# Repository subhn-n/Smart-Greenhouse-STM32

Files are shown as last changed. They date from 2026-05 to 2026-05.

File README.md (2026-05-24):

# 🌱 Smart Greenhouse Controller

<p align="center">
  
  
  
  
  
  
  
</p>

---

## 📖 Overview

This project is a **smart greenhouse controller** designed around an **STM32L476RG** microcontroller.  
The goal was to create an embedded system capable of:

- 🌡 Monitoring temperature
- 💧 Monitoring soil humidity
- ☀️ Measuring ambient light
- 🚿 Controlling a water pump
- 🌬 Controlling a cooling fan
- 💡 Controlling LED lighting using PWM
- 📱 Communicating wirelessly through Bluetooth

The project combines:

- Embedded programming
- Power electronics
- PCB design
- Sensor acquisition
- Bluetooth communication
- PWM control
- Rapid prototyping

---

# 🧠 System Architecture

<p align="center">
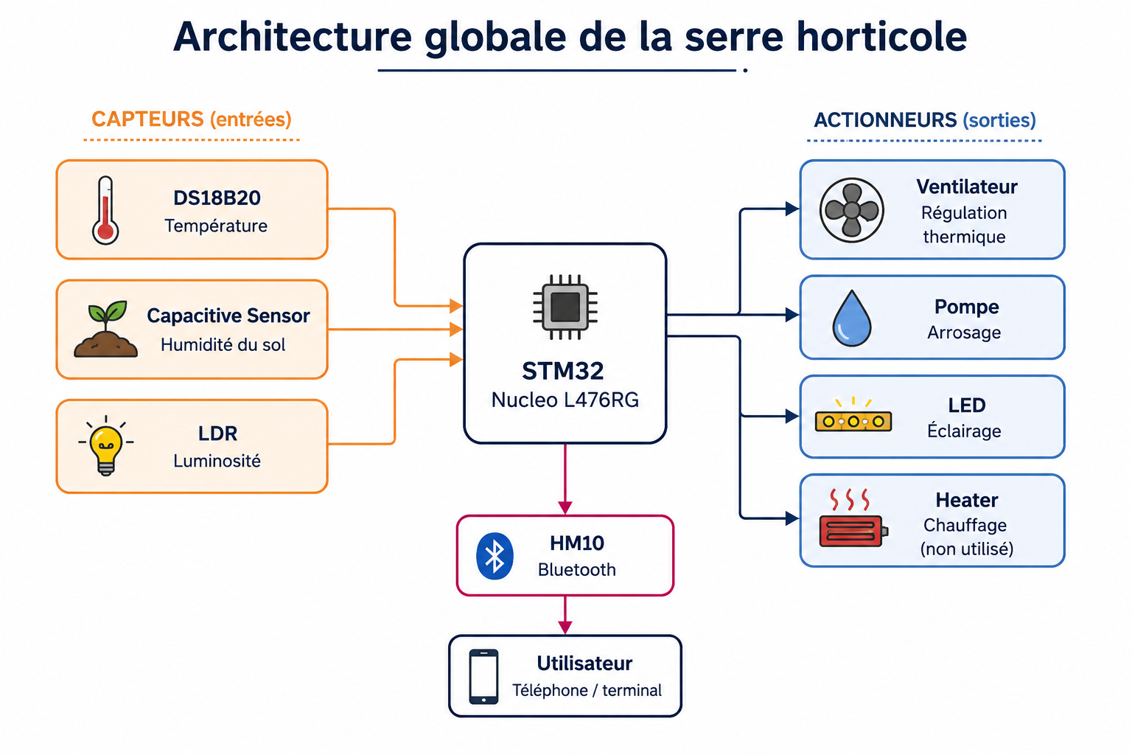
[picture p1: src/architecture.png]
  
</p>

The system is divided into several functional blocks:

- 🔋 Power PCB
- ⚡ Actuator PCB
- 🌱 Sensor PCB
- 💡 LED Control PCB
- 🧠 STM32 Main Controller

---

# 🔌 Hardware Used

## 🧠 Microcontroller

| Component | Description |
|---|---|
| STM32L476RG | Main embedded controller |

---

## 🌱 Sensors

| Sensor | Purpose |
|---|---|
| DS18B20 | Temperature measurement |
| Capacitive Soil Sensor V2.0 | Soil humidity measurement |
| LDR | Ambient light measurement |

---

## ⚡ Actuators

| Component | Purpose |
|---|---|
| 5V Water Pump | Irrigation |
| 12V Fan | Cooling |
| 12V LED Modules | Artificial lighting |

---

# 📡 Bluetooth Communication

The system communicates with a smartphone using a **HM10 BLE module**.

Commands can be sent directly from a mobile device:

```txt
PUMP_ON
PUMP_OFF
FAN_ON
FAN_OFF
TEMP?
HUM?
LIGHT?
LED:500
```

The STM32 then responds with sensor values or activates the requested actuator.

---

# 💡 PWM LED Control

LED brightness is controlled using PWM generated by **TIM3**.

```txt
LED:0      -> OFF
LED:250    -> 25%
LED:500    -> 50%
LED:999    -> 100%
```

---

# 🛠 PCB Design

The project originally started as a single large shield PCB.

To improve modularity and debugging, the system was redesigned into multiple smaller PCBs:

- Power PCB
- Sensor PCB
- Actuator PCB
- LED PCB

This modular architecture made:
- testing easier,
- debugging faster,
- integration cleaner.

<p align="center">
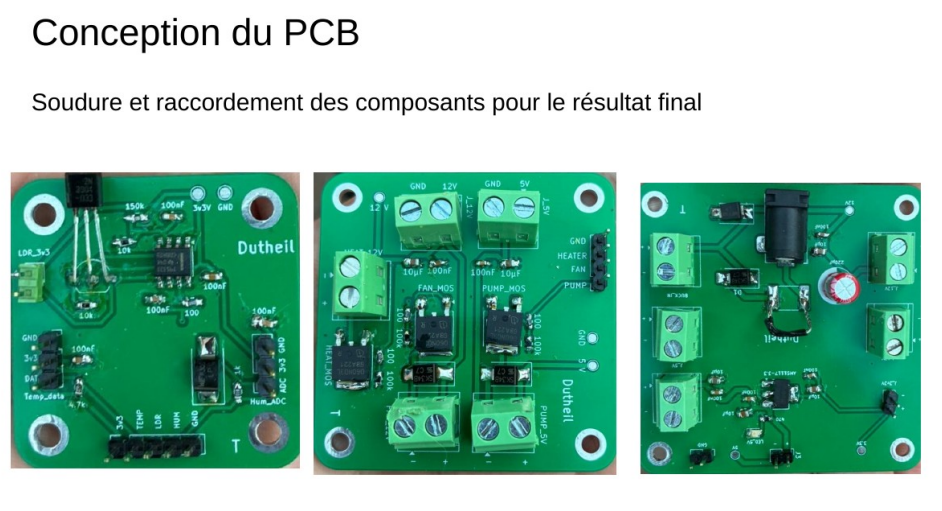
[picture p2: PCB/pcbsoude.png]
  
</p>

---

# 💻 Software

The firmware was developed using:

<p align="left">
  
  
  
  
</p>

Main software features:

- UART communication
- ADC acquisition
- PWM generation
- Threshold-based alerts
- Sensor data processing
- Bluetooth command parsing

---

# 📱 Android Application

An Android application was also started using:

<p align="left">
  
  
</p>

The goal was to create a dedicated greenhouse monitoring interface.

---

# 🧪 Testing

Each subsystem was validated independently:

- ✅ Pump control
- ✅ Fan control
- ✅ Bluetooth communication
- ✅ PWM LED control
- ✅ Temperature acquisition
- ✅ ADC acquisition
- ✅ Sensor threshold detection

The project was progressively integrated block-by-block during development.

---

# 🏗 Greenhouse Prototype

A physical greenhouse mockup was built to integrate the electronics into a realistic environment.

Materials used:

- Plexiglass
- Wood
- PVC bars
- Aluminum bars

<p align="center">
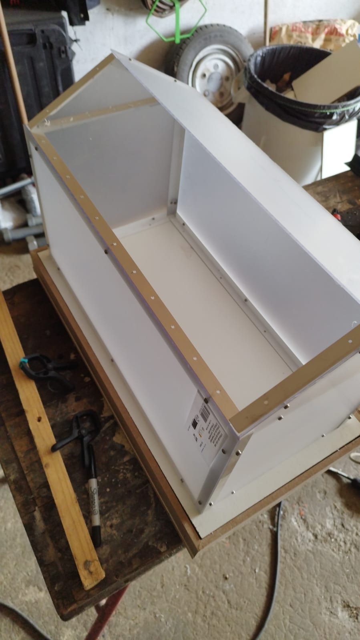
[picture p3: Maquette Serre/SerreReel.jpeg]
  
</p>

---

# 🚀 Future Improvements

- 📲 Complete Android app
- 🤖 Automatic greenhouse regulation
- 📈 Data logging

---

# 👨‍💻 Authors

- subhn-n
- Trifano

ENSEA - Embedded Systems Project 🌱

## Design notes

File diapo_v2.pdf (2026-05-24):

# Horticultural Greenhouse Project

## Sensors, control and remote monitoring

Goal: monitor temperature, soil moisture and light, then control the greenhouse actuators.

ENSEA - Electronics 1A | | | Team of 3 | | | Date: to complete ENSEA - Electronics 1A | Date: 21/05

What is a greenhouse? | 2

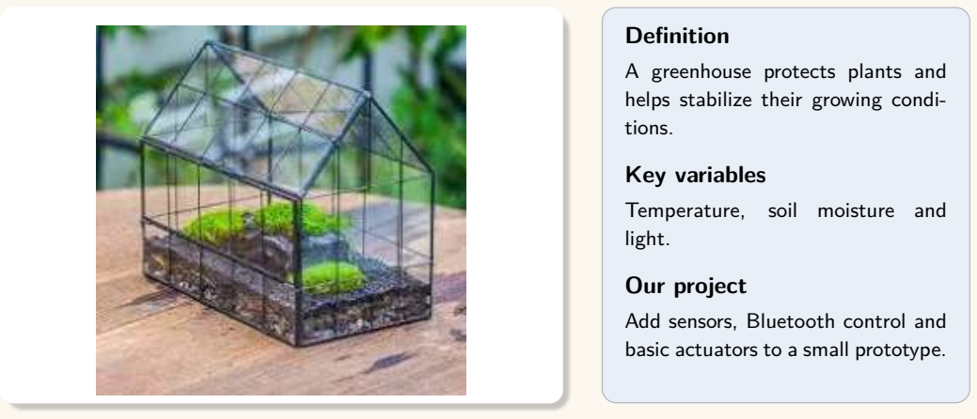
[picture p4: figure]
Definition; A greenhouse protects plants and helps stabilize their growing condi- tions.; Key variables; Temperature,; soil moisture and; light.; Our project; Add sensors, Bluetooth control and basic actuators to a small prototype.

## 3 Presentation structure

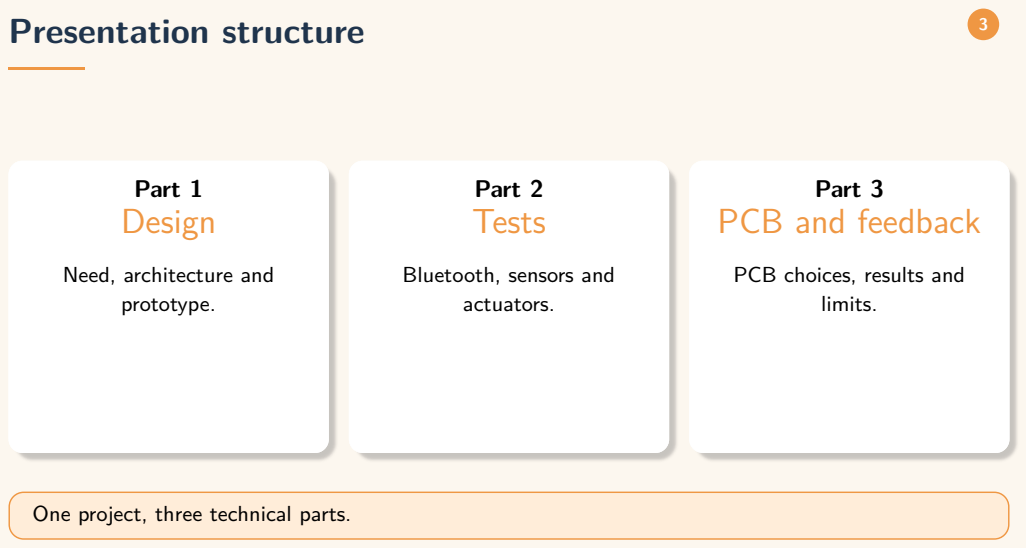
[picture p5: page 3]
Part 1 Design; prototype.; Part 2 Tests; actuators.; Part 3; limits.

PCB and feedback

Need, architecture and

Bluetooth, sensors and

PCB choices, results and

One project, three technical parts.

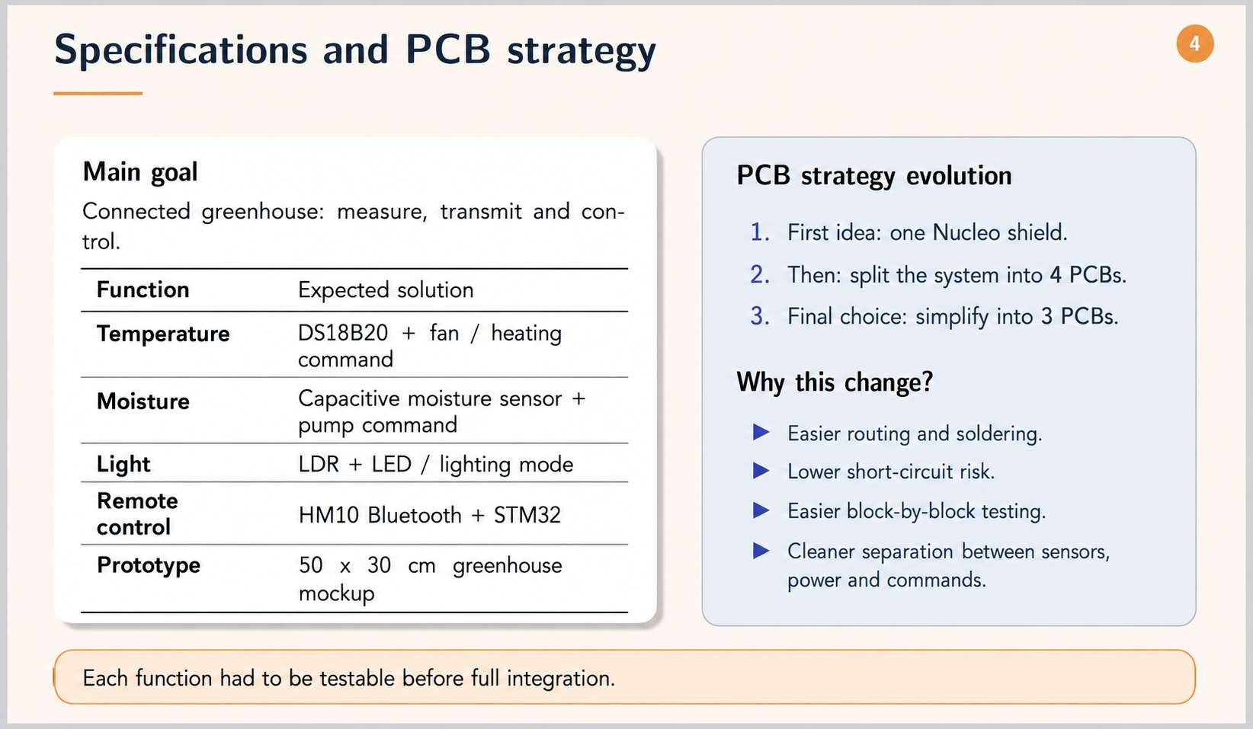
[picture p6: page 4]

# Part 1

## Need and system design

What problem are we trying to solve, and how is the system organized?

## 6 Context and specifications

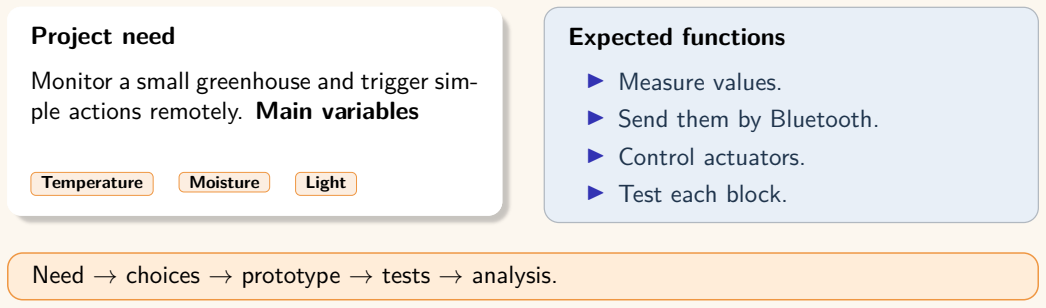
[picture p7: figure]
Project need; ple actions remotely. Main variables; Temperature; Moisture; Light; Expected functions; ▶ Measure values.; ▶ Send them by Bluetooth.; ▶ Control actuators.; ▶ Test each block.

Monitor a small greenhouse and trigger sim-

Need → choices → prototype → tests → analysis.

## 7 System architecture

The STM32 is the central block: it reads sensors, controls outputs and communicates with the

## 8 Sensors selected

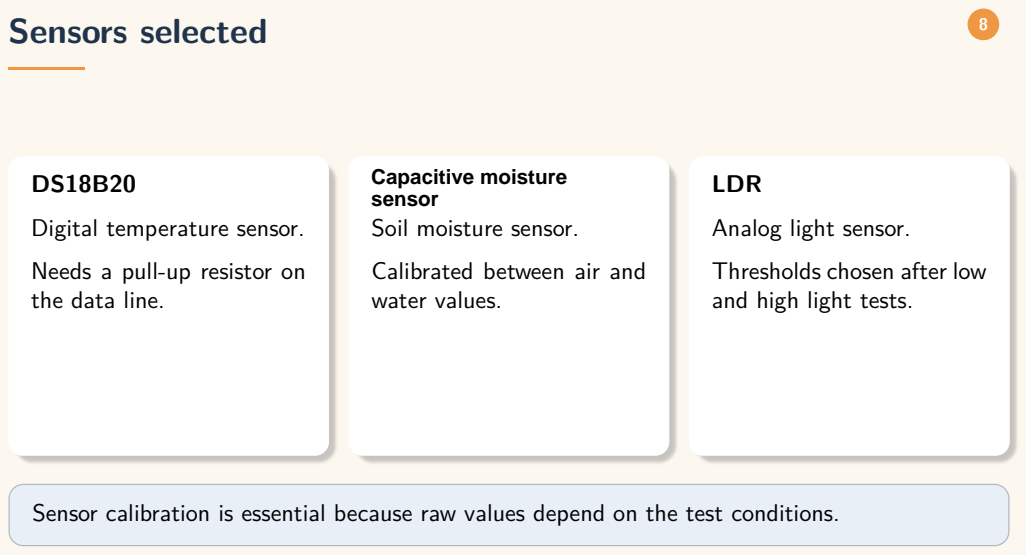
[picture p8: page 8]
LDR

Capacitive moisture
sensor
Soil moisture sensor.

Digital temperature sensor.

Analog light sensor.

Needs a pull-up resistor on
the data line.

Calibrated between air and
water values.

Thresholds chosen after low
and high light tests.

Sensor calibration is essential because raw values depend on the test conditions.

## 9 Prototype model

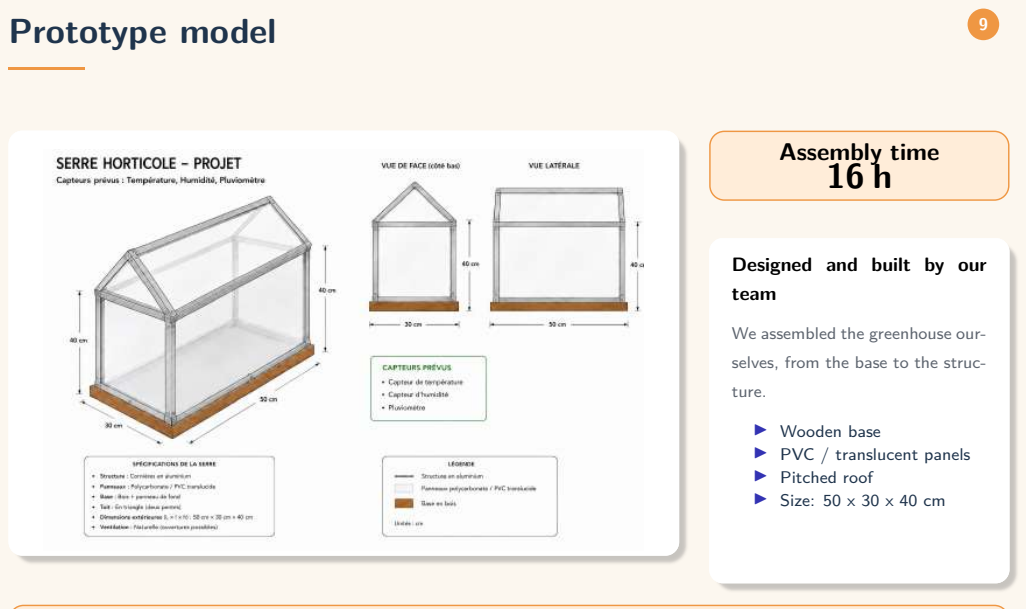
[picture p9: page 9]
Assembly time 16 h; ture.

Designed and built by our
team

We assembled the greenhouse our-

selves, from the base to the struc-

▶ Wooden base
▶ PVC / translucent panels
▶ Pitched roof
▶ Size: 50 x 30 x 40 cm

## 10 Final prototype built by our team

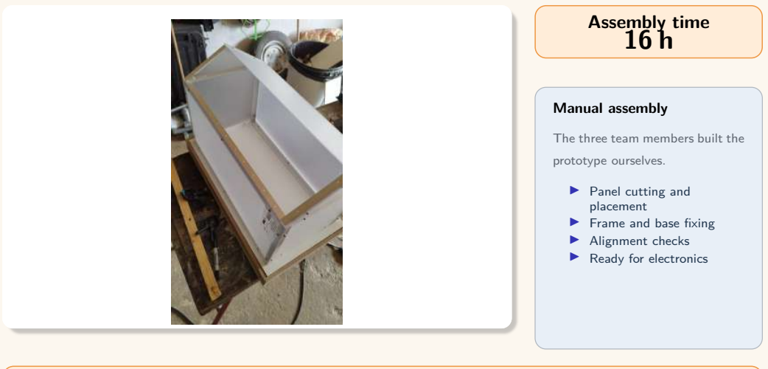
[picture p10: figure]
Assembly time 16 h; Manual assembly; The three team members built the; prototype ourselves.; ▶ Panel cutting and; placement ▶ Frame and base fixing; ▶ Alignment checks; ▶ Ready for electronics

# Part 2

## Control, Bluetooth and tests

How do we command the system and prove that each block works?

## 12 Bluetooth module HM10

Bluetooth link between the smartphone and the STM32.

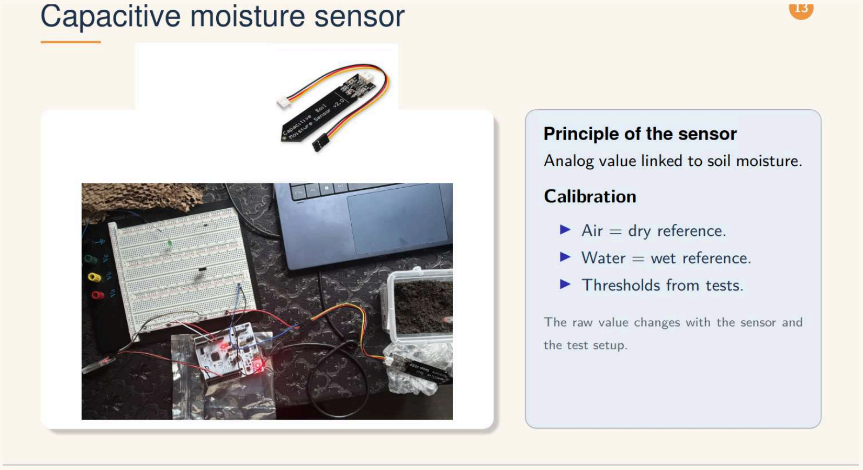
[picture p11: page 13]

Moisture sensor calibration | 14

These two cases define the usable range for the humidity measurement.

Moisture Bluetooth result | 15

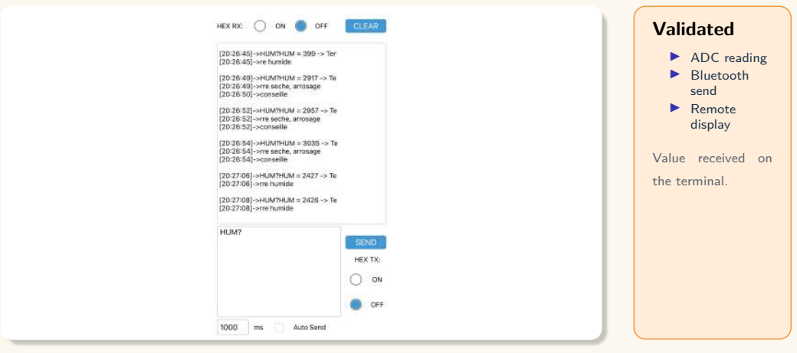
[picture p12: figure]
Validated; ▶ ADC reading; ▶ Bluetooth; send ▶ Remote; display; Value received on; the terminal.

## 16 Temperature sensor DS18B20

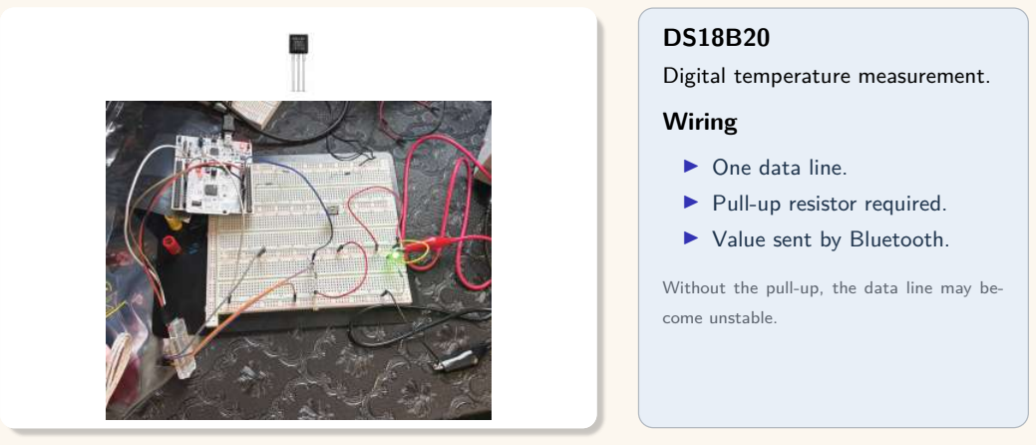
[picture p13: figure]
Digital temperature measurement.; Wiring; ▶ One data line.; ▶ Pull-up resistor required.; ▶ Value sent by Bluetooth.; come unstable.

Without the pull-up, the data line may be-

## 17 Temperature measurement test

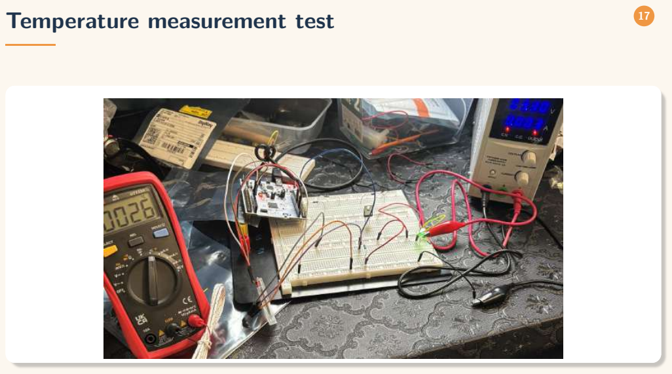
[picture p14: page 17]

## 18 Temperature Bluetooth response

## 19 Light sensor LDR

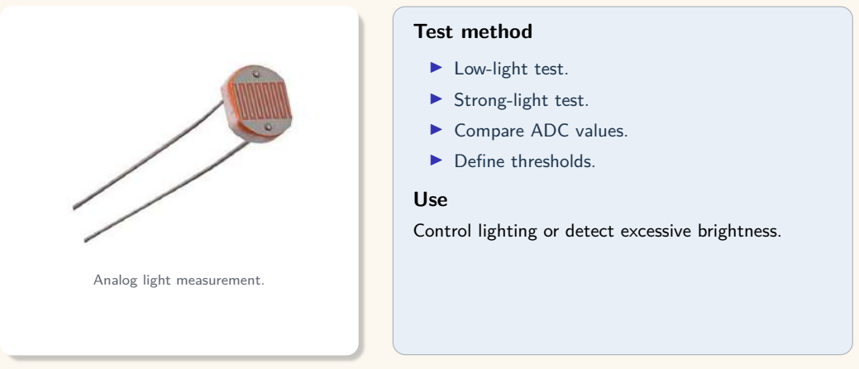
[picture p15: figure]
Analog light measurement.; Test method; ▶ Low-light test.; ▶ Strong-light test.; ▶ Compare ADC values.; ▶ Define thresholds.; Use

Control lighting or detect excessive brightness.

## 20 LDR calibration tests

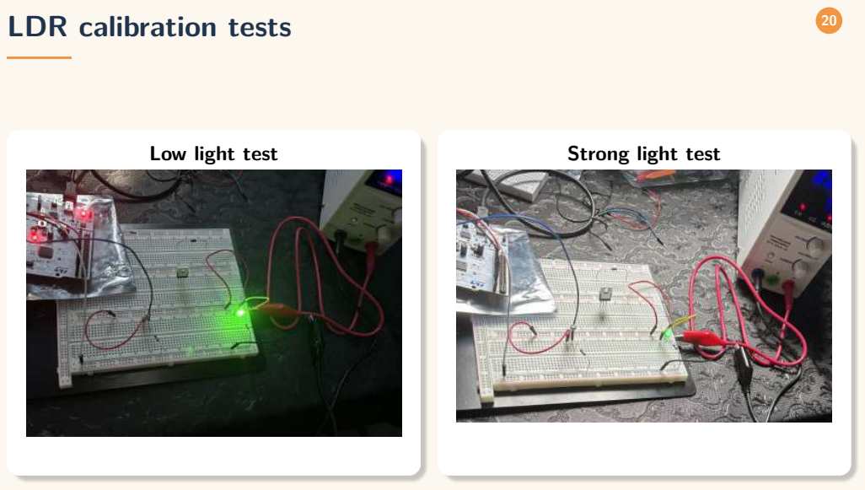
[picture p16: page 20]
Low light test; Strong light test

## 21 LDR Bluetooth results

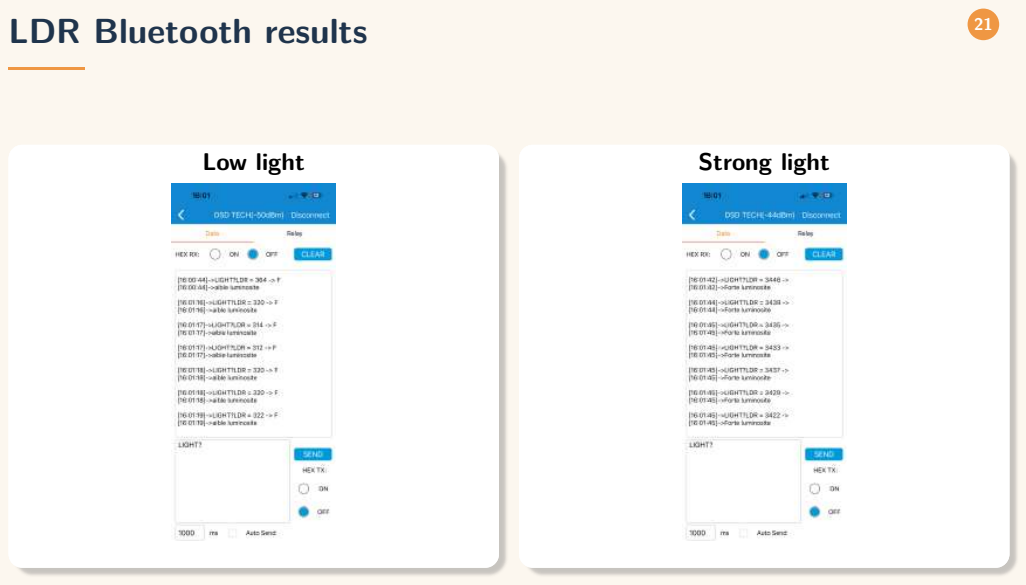
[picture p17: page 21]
Low light; Strong light

## 22 LDR thresholds retained

The STM32 can apply these thresholds to con-

## 23 Pump and fan tests

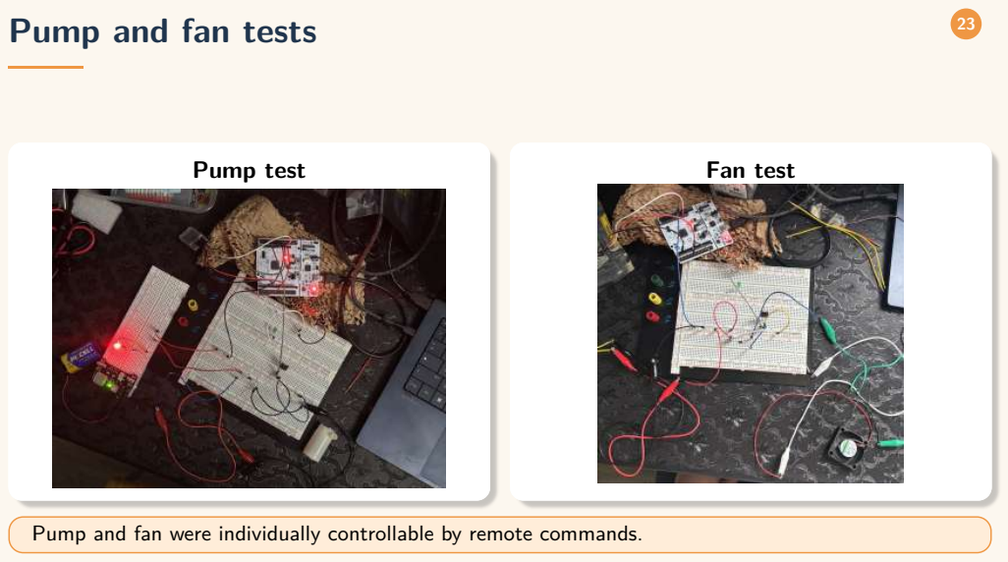
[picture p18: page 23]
Pump test; Fan test

Pump and fan were individually controllable by remote commands.

## 24 Fan Bluetooth result

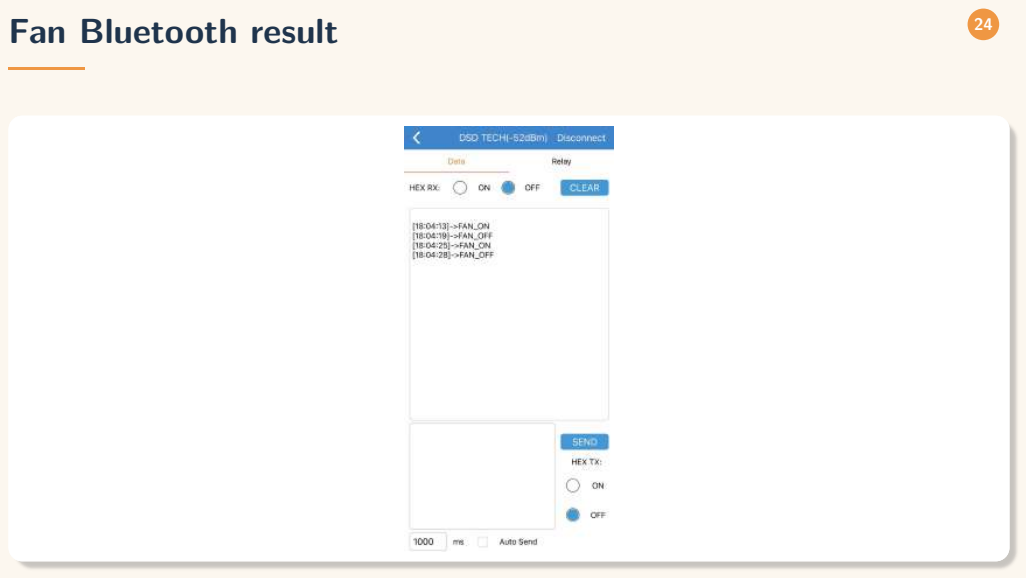
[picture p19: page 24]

## 25 Component test summary

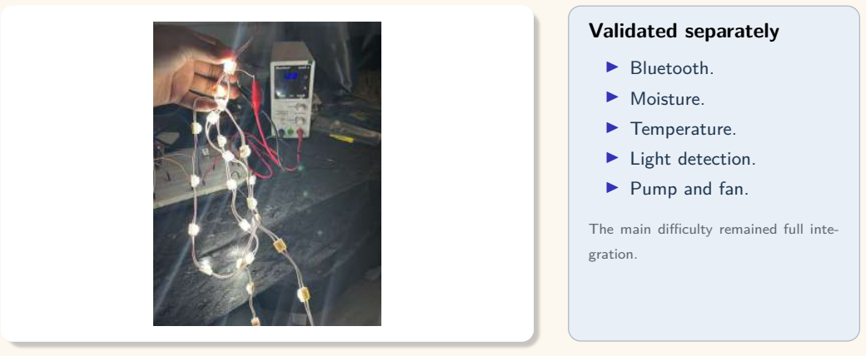
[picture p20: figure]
Validated separately; ▶ Bluetooth.; ▶ Moisture.; ▶ Temperature.; ▶ Light detection.; ▶ Pump and fan.; The main difficulty remained full inte-; gration.

# Part 3

## Prototype, PCB and feedback

What was built, what worked, and what should be improved?

## 27 PCB assembly and connection

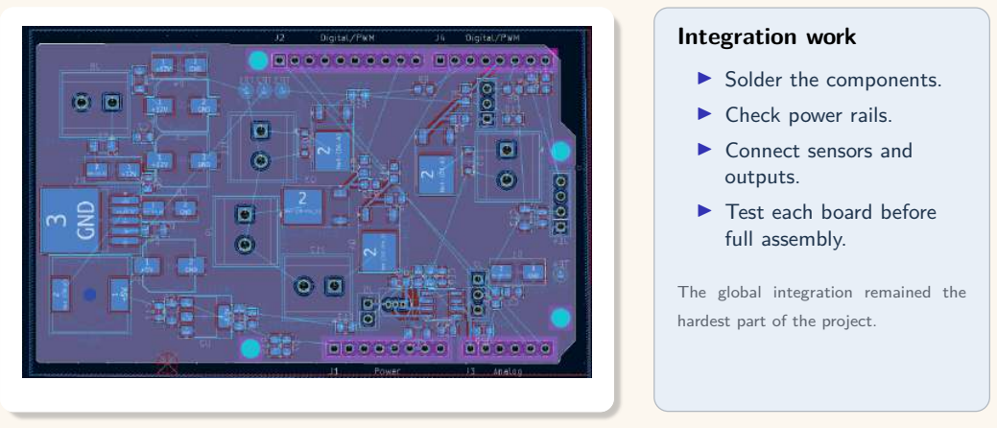
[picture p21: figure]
Integration work; ▶ Solder the components.; ▶ Check power rails.; ▶ Connect sensors and; outputs.; ▶ Test each board before; full assembly.; The global integration remained the; hardest part of the project.

## 28 PCB design: first approach

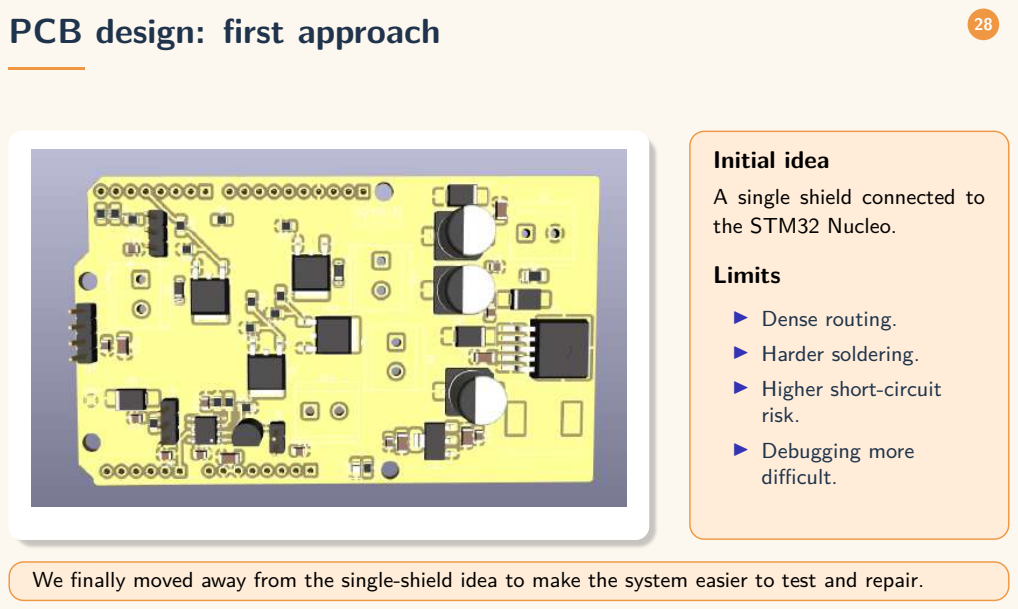
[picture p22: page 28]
Initial idea; Limits

A single shield connected to
the STM32 Nucleo.

▶ Dense routing.
▶ Harder soldering.
▶ Higher short-circuit
risk.
▶ Debugging more
difficult.

We finally moved away from the single-shield idea to make the system easier to test and repair.

## 29 Complete schematic overview

## 30 Electronic schematics: power and sensors

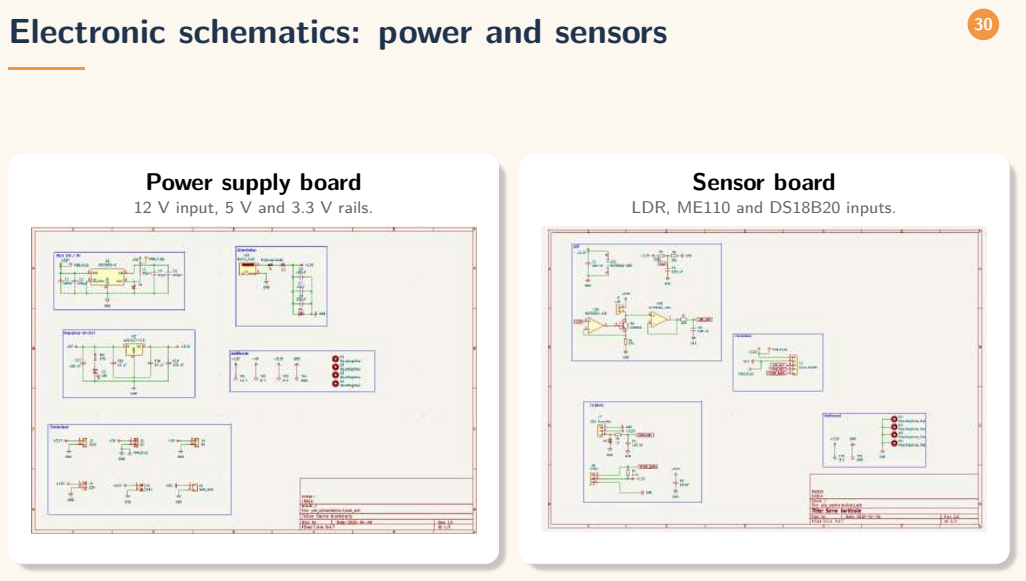
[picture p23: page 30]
Sensor board

Power supply board
12 V input, 5 V and 3.3 V rails.

LDR, ME110 and DS18B20 inputs.

## 31 Electronic schematics: outputs

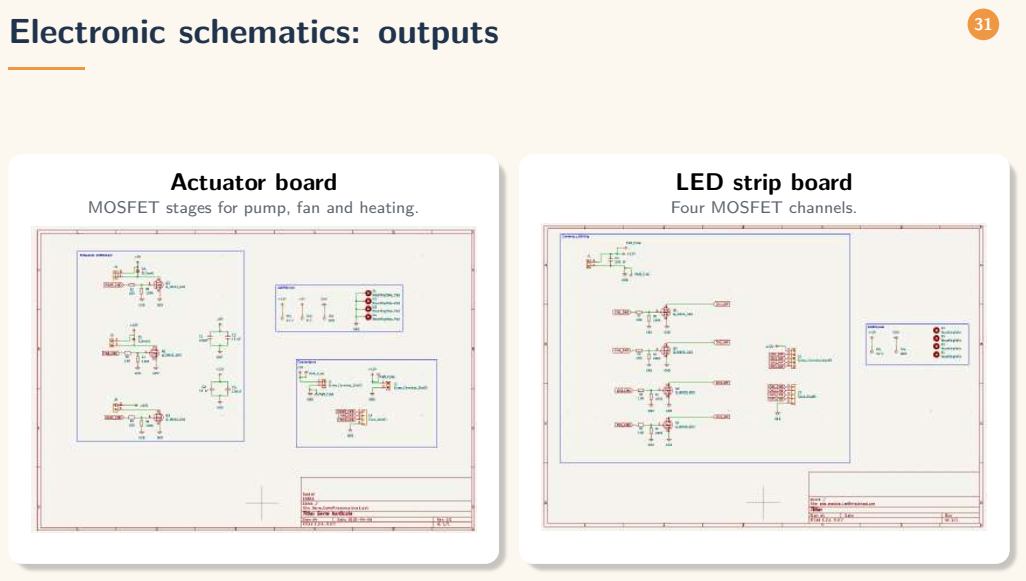
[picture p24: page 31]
Actuator board

LED strip board
Four MOSFET channels.

MOSFET stages for pump, fan and heating.

## 32 PCB layout: split into functional boards

Final strategy: separate sensors, power supply and actuator command stages.

## 33 Fabricated PCB boards

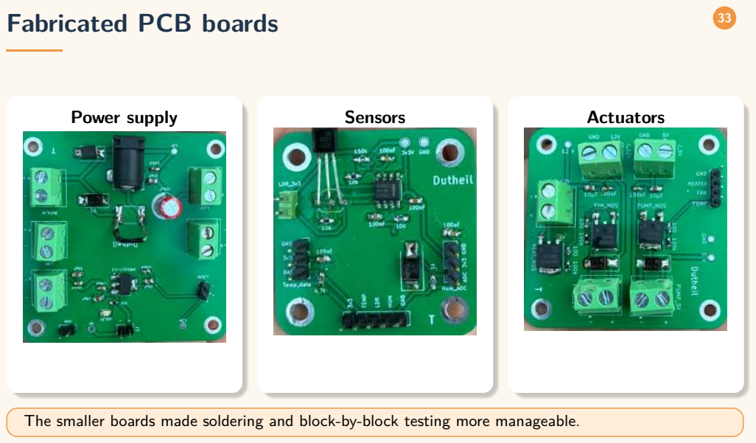
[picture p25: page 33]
Power supply; Sensors; Actuators

The smaller boards made soldering and block-by-block testing more manageable.

## 34 Results, limits and possible causes

Main limit

The complete system was not fully reliable.

The exact cause was not identified before the end of the project.

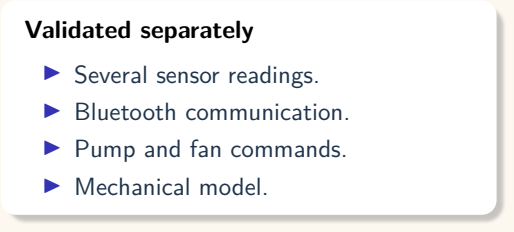
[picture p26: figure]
Validated separately; ▶ Several sensor readings.; ▶ Bluetooth communication.; ▶ Pump and fan commands.; ▶ Mechanical model.

Possible causes: weak solder joint, wiring error, power issue, software timing issue or Bluetooth conflict.

## 35 Conclusion and next steps

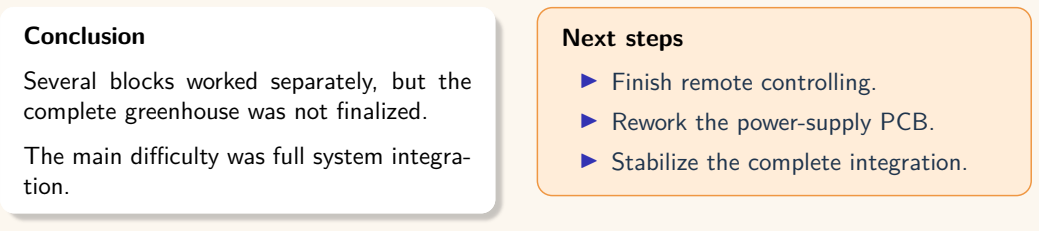
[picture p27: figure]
Conclusion; complete greenhouse was not finalized.; tion.; Next steps; ▶ Finish remote controlling.; ▶ Rework the power-supply PCB.; ▶ Stabilize the complete integration.

Several blocks worked separately, but the

The main difficulty was full system integra-

# Questions?

Thank you for your attention.

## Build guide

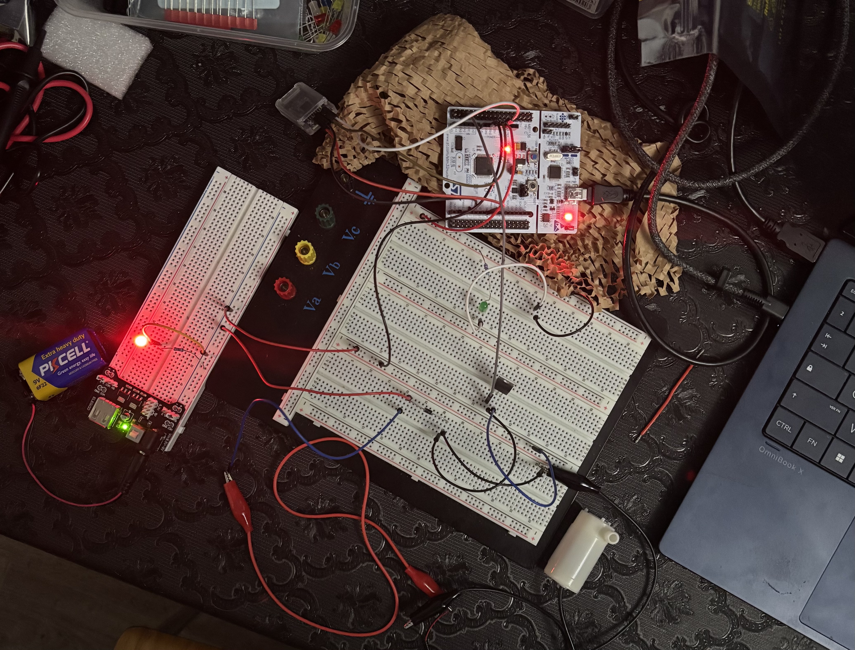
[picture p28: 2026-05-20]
Test_composant_individuel/PUMP/montage.jpeg

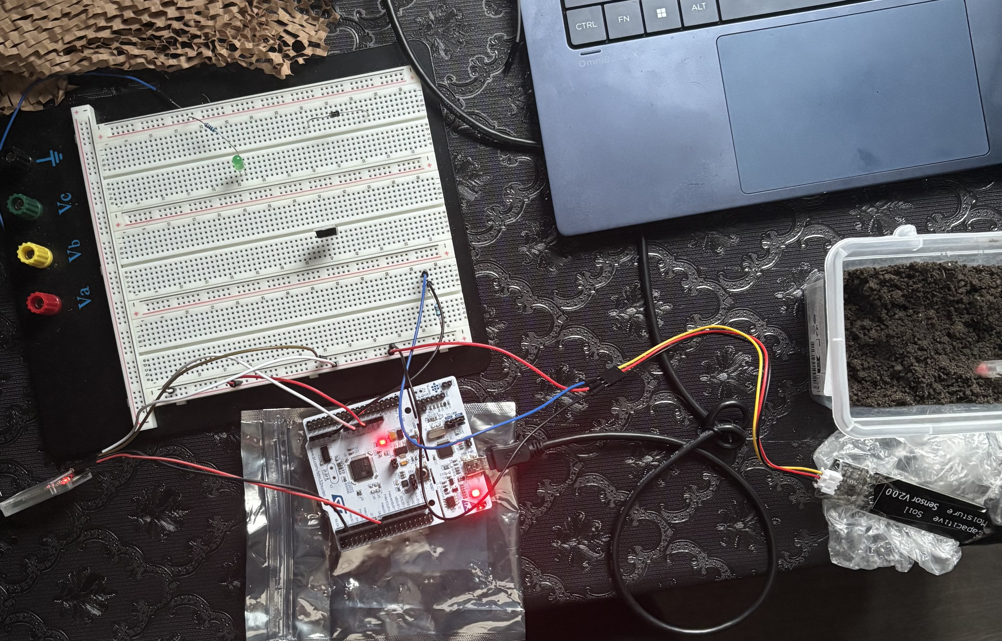
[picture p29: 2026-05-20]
Test_composant_individuel/Moisture_Sensor/montage.jpeg

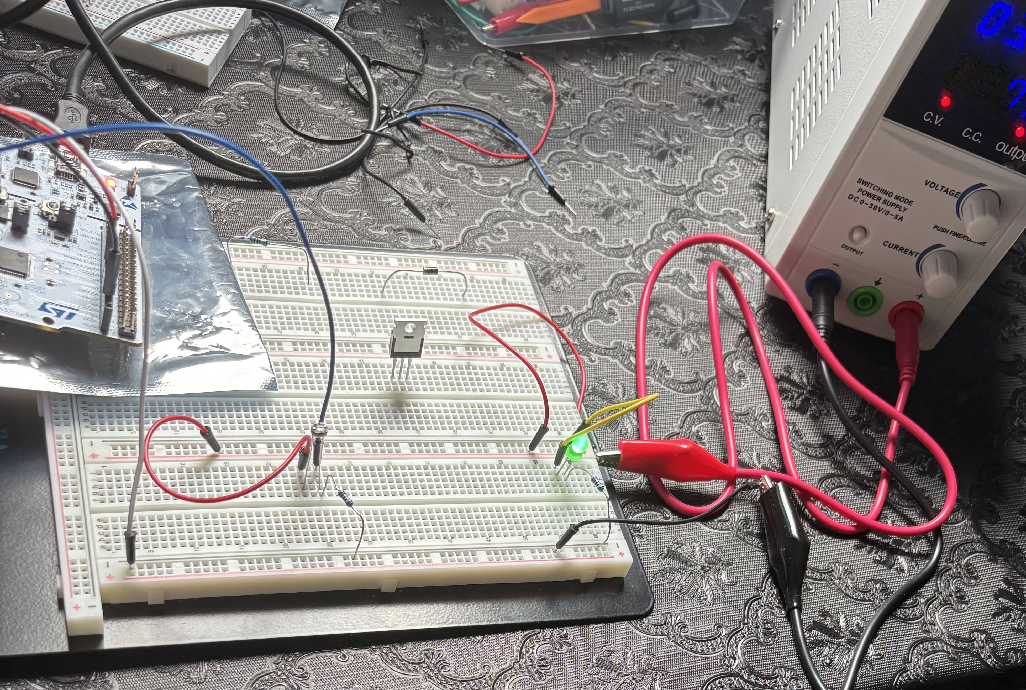
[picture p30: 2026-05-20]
Test_composant_individuel/LDR/montage_LIGHT.jpeg

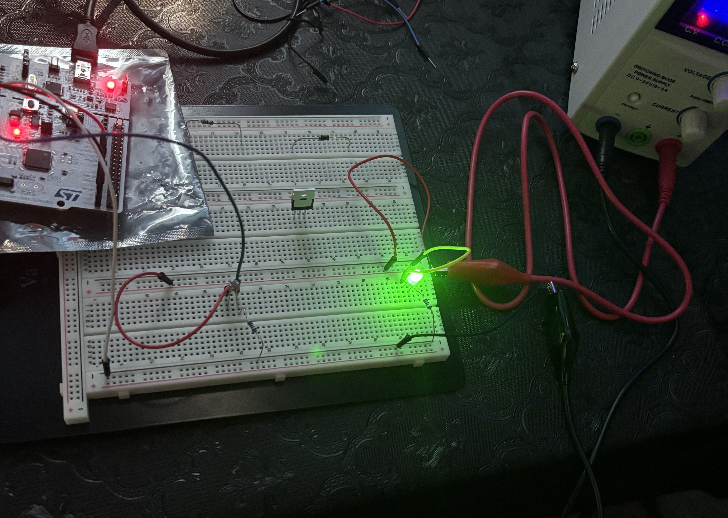
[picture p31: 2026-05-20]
Test_composant_individuel/LDR/montage_DARK.jpeg

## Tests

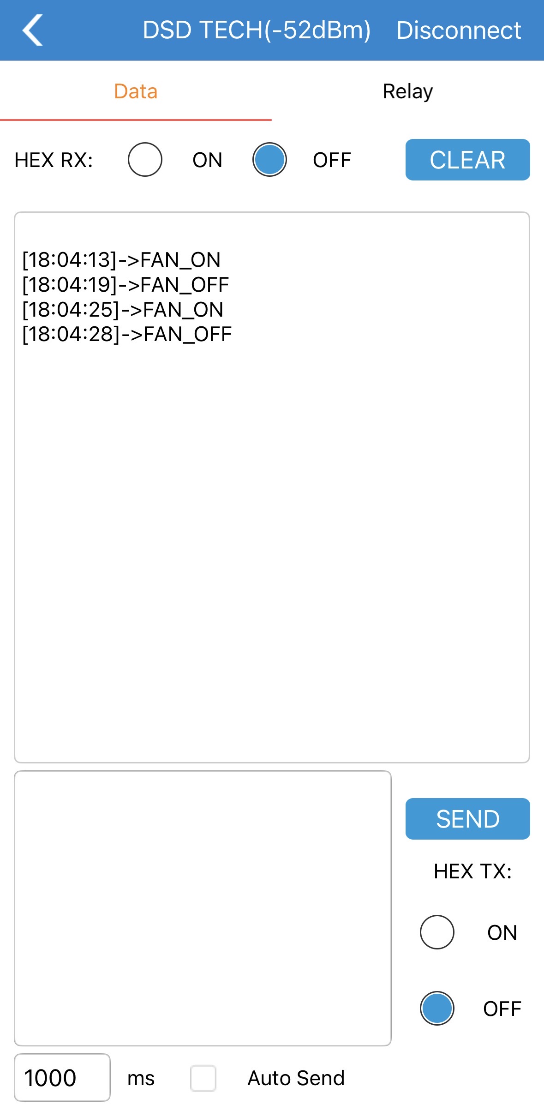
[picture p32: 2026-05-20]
Test_composant_individuel/FAN/data APP_V1.jpeg

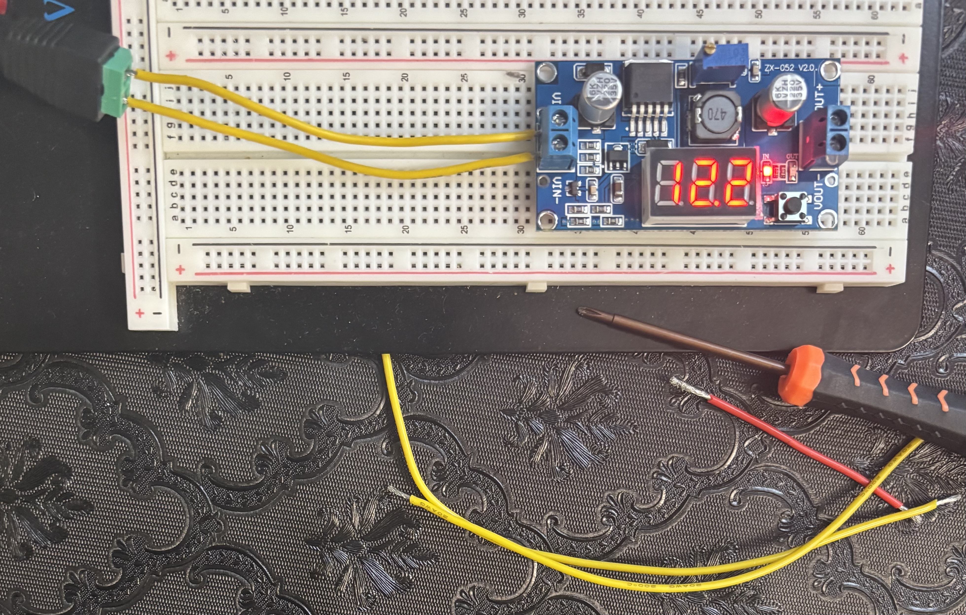
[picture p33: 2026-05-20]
Test_composant_individuel/Regulator/Vin_12V.jpeg

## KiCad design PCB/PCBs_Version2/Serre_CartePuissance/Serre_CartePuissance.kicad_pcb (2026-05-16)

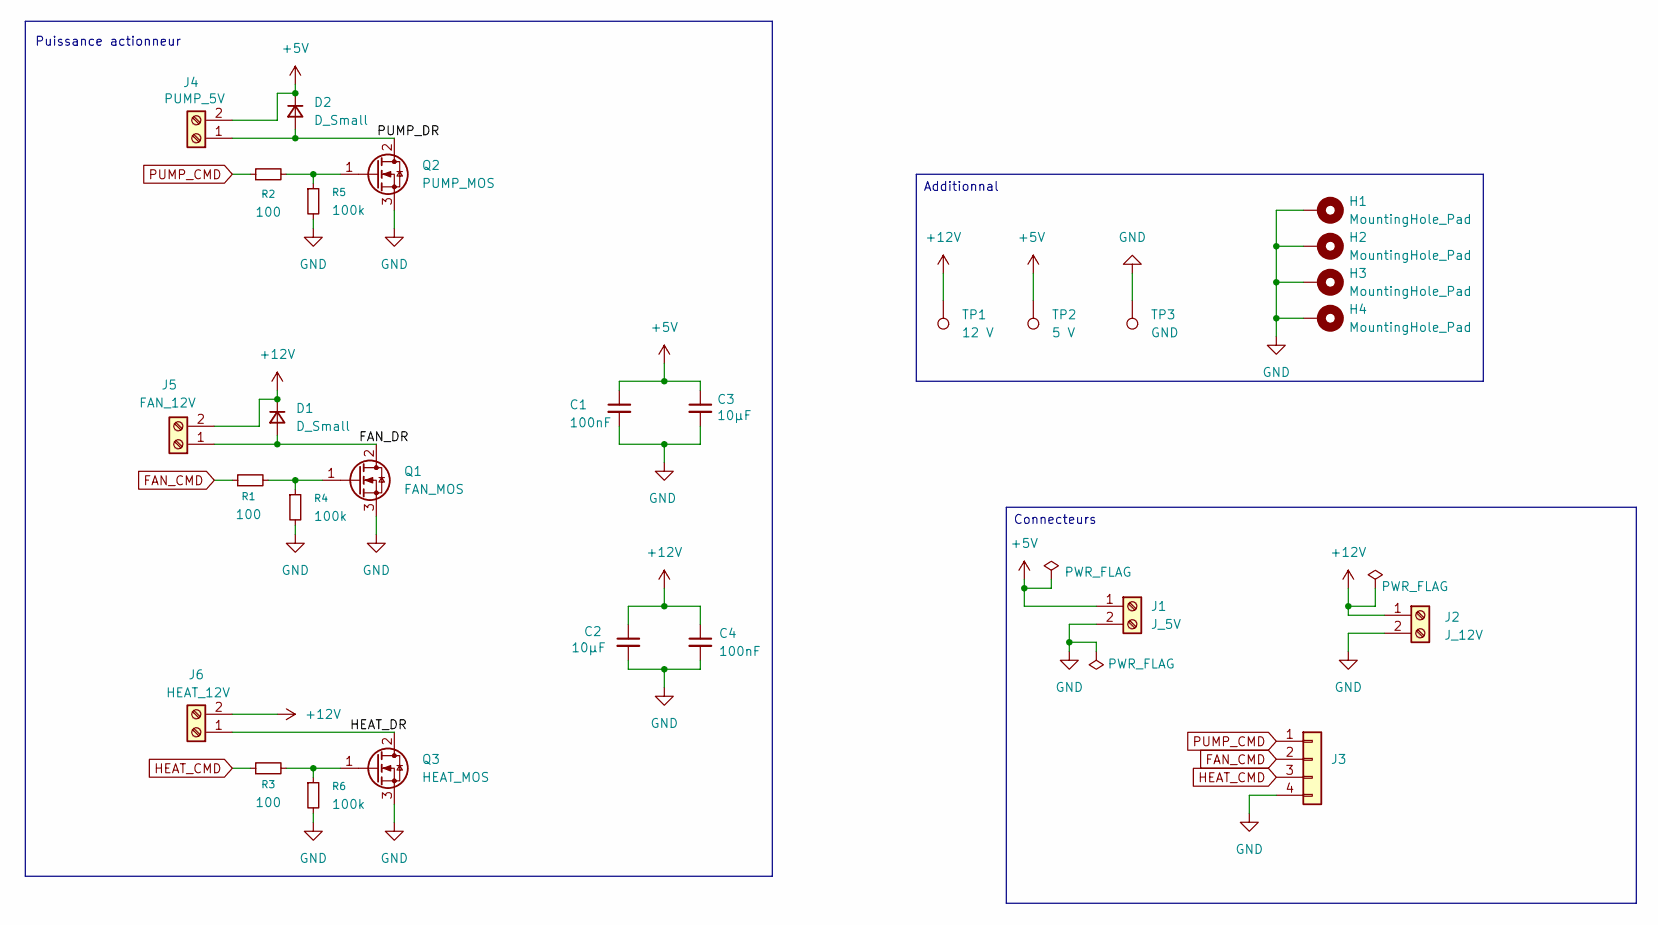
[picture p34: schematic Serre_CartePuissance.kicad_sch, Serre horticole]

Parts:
C1, C4: 100nF; C_0603_1608Metric_Pad1.08x0.95mm_HandSolder
C2, C3: 10µF; C_0805_2012Metric_Pad1.18x1.45mm_HandSolder
D1, D2: D_Small; D_SMB_Handsoldering
H1, H2, H3, H4: MountingHole_Pad; MountingHole_3.2mm_M3_DIN965_Pad
J1: J_5V; TerminalBlock_CUI_TB007-508-02_1x02_P5.08mm_Horizontal
J2: J_12V; TerminalBlock_CUI_TB007-508-02_1x02_P5.08mm_Horizontal
J3: Conn_01x04; PinSocket_1x04_P2.54mm_Vertical
J4: PUMP_5V; TerminalBlock_CUI_TB007-508-02_1x02_P5.08mm_Horizontal
J5: FAN_12V; TerminalBlock_CUI_TB007-508-02_1x02_P5.08mm_Horizontal
J6: HEAT_12V; TerminalBlock_CUI_TB007-508-02_1x02_P5.08mm_Horizontal
Q1: FAN_MOS; TO-252-2
Q2: PUMP_MOS; TO-252-2
Q3: HEAT_MOS; TO-252-2
R1, R2, R3: 100; R_0603_1608Metric_Pad0.98x0.95mm_HandSolder
R4, R5, R6: 100k; R_0603_1608Metric_Pad0.98x0.95mm_HandSolder
TP1: 12 V; TestPoint_Pad_D1.5mm
TP2: 5 V; TestPoint_Pad_D1.5mm
TP3: GND; TestPoint_Pad_D1.5mm

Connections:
+5V: C1.1, C3.1, D2.1 (K), J1.1, J4.2, TP2.1
+12V: C2.1, C4.1, D1.1 (K), J2.1, J5.2, J6.2, TP1.1
/FAN_DR: D1.2 (A), J5.1, Q1.2 (D)
/HEAT_DR: J6.1, Q3.2 (D)
/PUMP_DR: D2.2 (A), J4.1, Q2.2 (D)
FAN_CMD: J3.2, R1.1
GND: C1.2, C2.2, C3.2, C4.2, H1.1, H2.1, H3.1, H4.1, J1.2, J2.2, J3.4, Q1.3 (S), Q2.3 (S), Q3.3 (S), R4.2, R5.2, R6.2, TP3.1
HEAT_CMD: J3.3, R3.1
unnamed: Q1.1 (G), R1.2, R4.1
unnamed: Q2.1 (G), R2.2, R5.1
unnamed: Q3.1 (G), R3.2, R6.1
PUMP_CMD: J3.1, R2.1

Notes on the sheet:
Puissance actionneur
Connecteurs
Additionnal

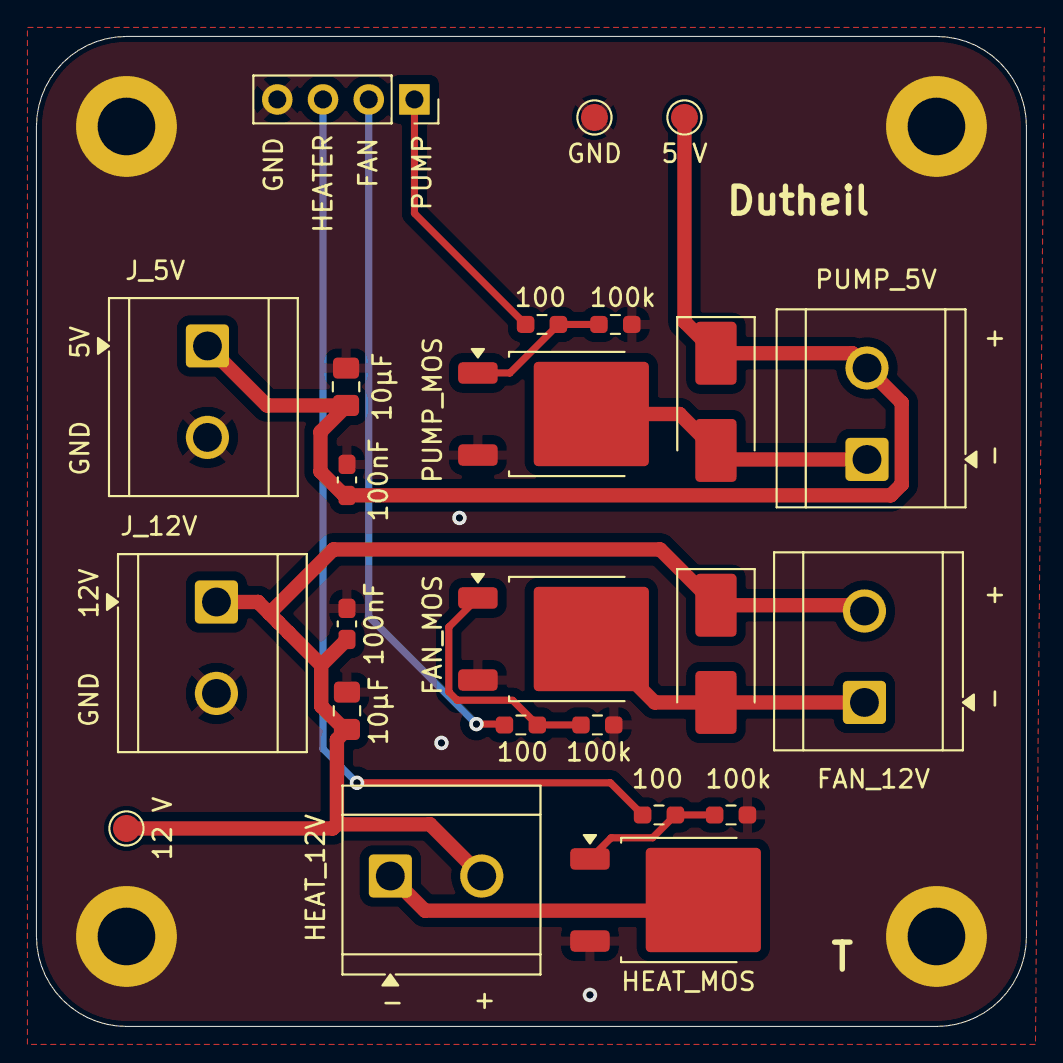
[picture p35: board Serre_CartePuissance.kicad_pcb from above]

Board: 2 copper layers, 55.0 x 55.0 mm, 28 parts (0 on the bottom side), 12 nets.

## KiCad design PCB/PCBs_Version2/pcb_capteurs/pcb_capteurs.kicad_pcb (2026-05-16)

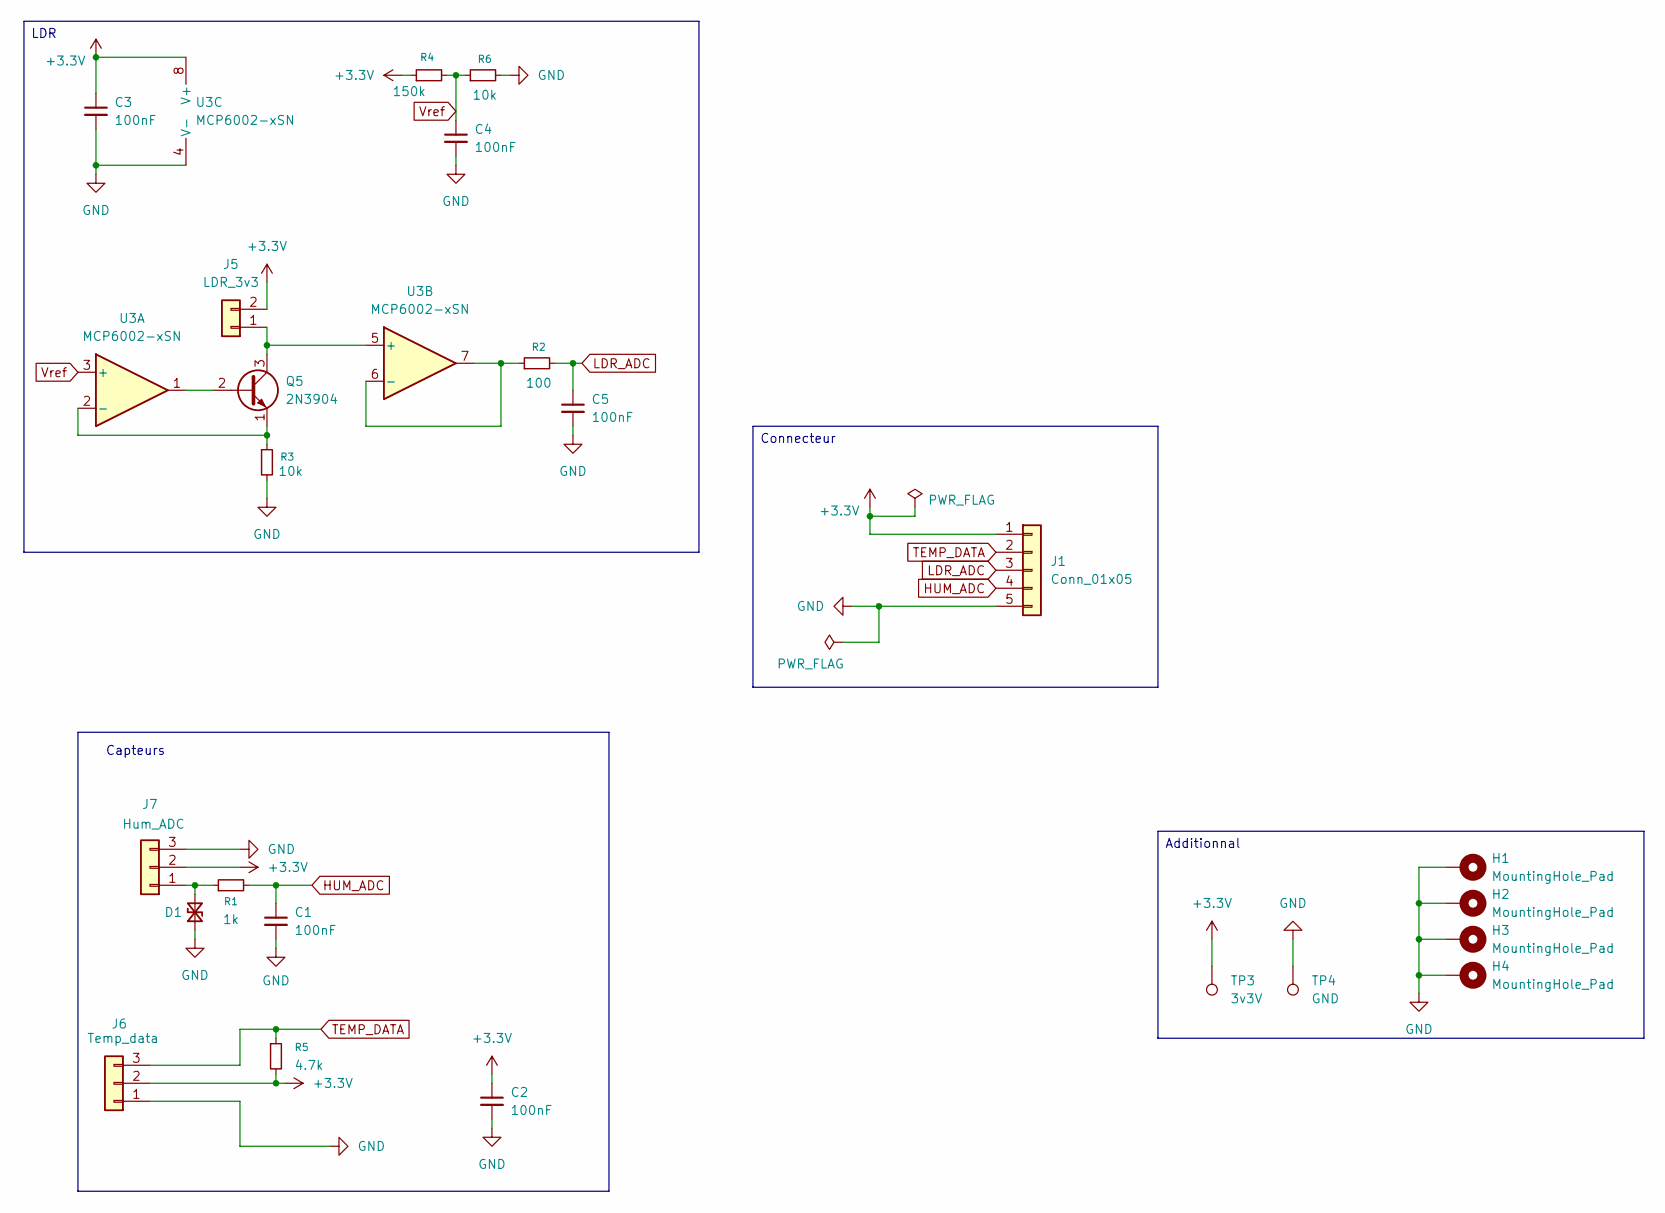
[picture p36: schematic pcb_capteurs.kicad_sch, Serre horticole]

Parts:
C1, C2, C3, C4, C5: 100nF; C_0603_1608Metric_Pad1.08x0.95mm_HandSolder
D1: D_TVS_Small; D_SMB_Handsoldering
H1, H2, H3, H4: MountingHole_Pad; MountingHole_3.2mm_M3_DIN965_Pad
J1: Conn_01x05; PinSocket_1x05_P2.54mm_Vertical
J5: LDR_3v3; PinSocket_1x02_P2.54mm_Vertical
J6: Temp_data; PinSocket_1x03_P2.54mm_Vertical
J7: Hum_ADC; PinSocket_1x03_P2.54mm_Vertical
Q5: 2N3904; TO-92_Inline_Wide
R1: 1k; R_0603_1608Metric_Pad0.98x0.95mm_HandSolder
R2: 100; R_0603_1608Metric_Pad0.98x0.95mm_HandSolder
R3, R6: 10k; R_0603_1608Metric_Pad0.98x0.95mm_HandSolder
R4: 150k; R_0603_1608Metric_Pad0.98x0.95mm_HandSolder
R5: 4.7k; R_0603_1608Metric_Pad0.98x0.95mm_HandSolder
TP3: 3v3V; TestPoint_Pad_D1.5mm
TP4: GND; TestPoint_Pad_D1.5mm
U3: MCP6002-xSN; SOIC-8_3.9x4.9mm_P1.27mm

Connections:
+3.3V: C2.1, C3.1, J1.1, J5.2, J6.2, J7.2, R4.1, R5.2, TP3.1, U3.8 (V+)
GND: C1.2, C2.2, C3.2, C4.2, C5.2, D1.1 (A1), H1.1, H2.1, H3.1, H4.1, J1.5, J6.1, J7.3, R3.2, R6.2, TP4.1, U3.4 (V-)
HUM_ADC: C1.1, J1.4, R1.2
LDR_ADC: C5.1, J1.3, R2.2
unnamed: D1.2 (A2), J7.1, R1.1
unnamed: J5.1, Q5.3 (C), U3.5 (+)
unnamed: Q5.2 (B), U3.1
unnamed: Q5.1 (E), R3.1, U3.2 (-)
unnamed: R2.1, U3.6 (-), U3.7
TEMP_DATA: J1.2, J6.3, R5.1
Vref: C4.1, R4.2, R6.1, U3.3 (+)

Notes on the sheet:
Capteurs
Additionnal
Connecteur
LDR

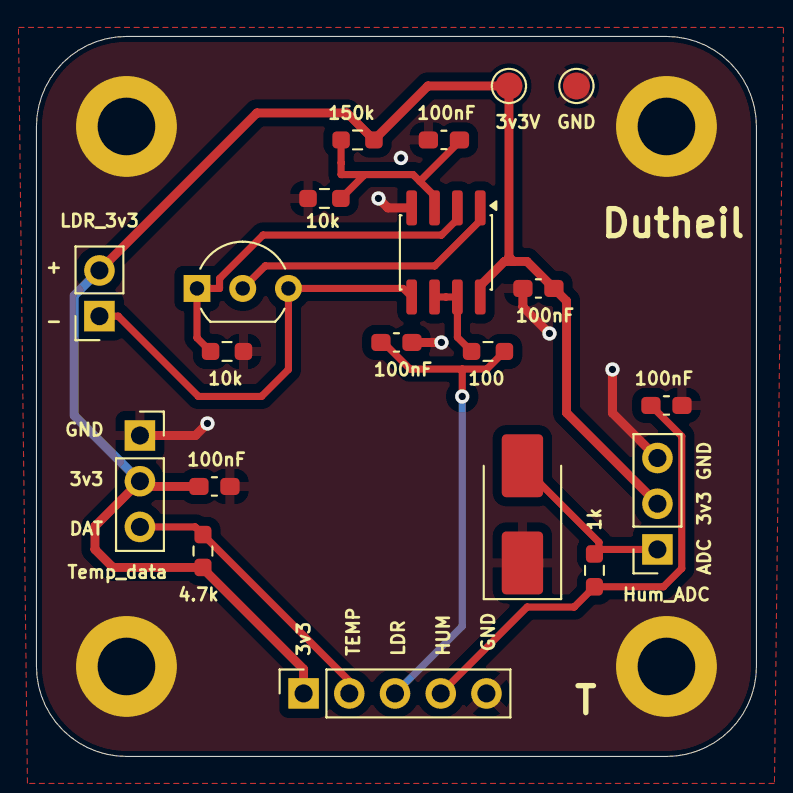
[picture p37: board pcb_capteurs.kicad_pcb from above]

Board: 2 copper layers, 40.0 x 40.0 mm, 24 parts (0 on the bottom side), 11 nets.

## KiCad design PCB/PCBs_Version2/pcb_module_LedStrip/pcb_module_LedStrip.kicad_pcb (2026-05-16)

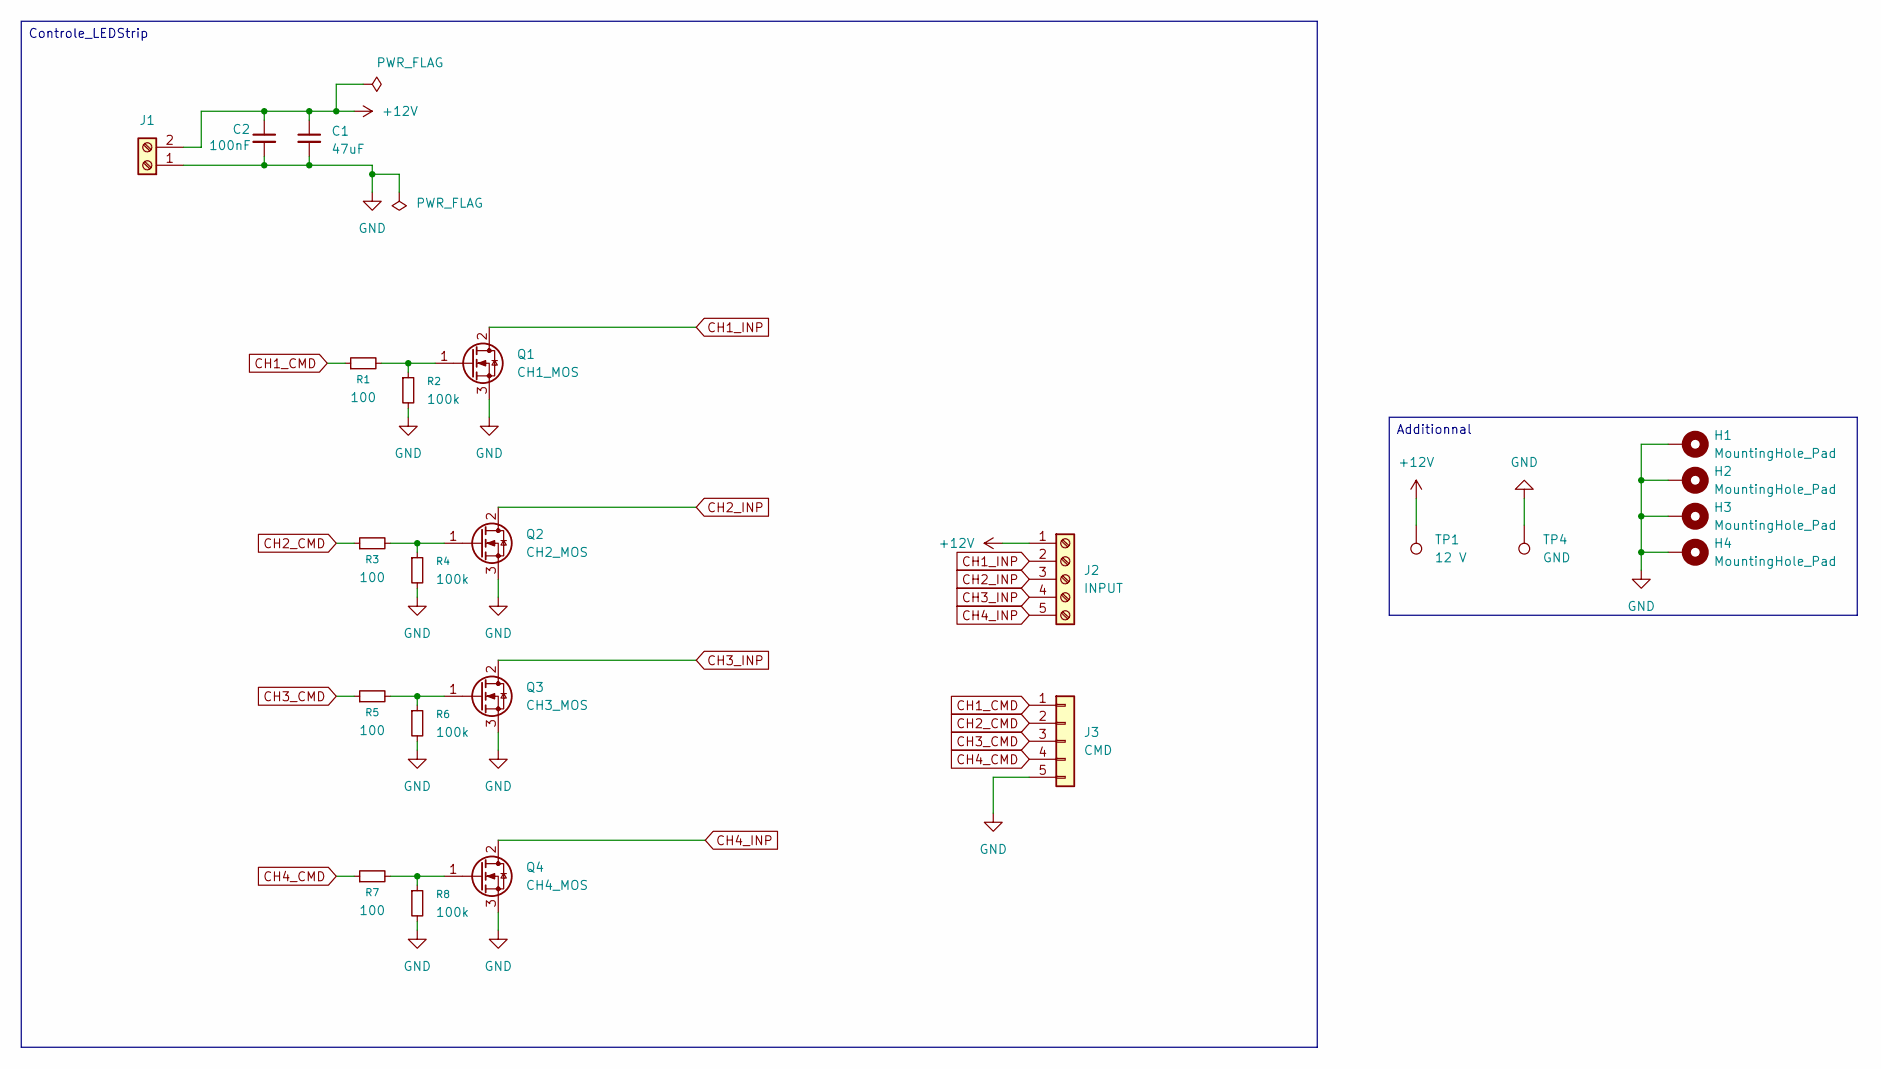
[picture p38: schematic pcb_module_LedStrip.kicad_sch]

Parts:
C1: 47uF; CP_Radial_D5.0mm_P2.00mm
C2: 100nF; C_0603_1608Metric_Pad1.08x0.95mm_HandSolder
H1, H2, H3, H4: MountingHole_Pad; MountingHole_3.2mm_M3_DIN965_Pad
J1: Screw_Terminal_01x02; TerminalBlock_CUI_TB007-508-02_1x02_P5.08mm_Horizontal
J2: INPUT; TerminalBlock_CUI_TB007-508-05_1x05_P5.08mm_Horizontal
J3: CMD; PinSocket_1x05_P2.54mm_Vertical
Q1: CH1_MOS; TO-252-2
Q2: CH2_MOS; TO-252-2
Q3: CH3_MOS; TO-252-2
Q4: CH4_MOS; TO-252-2
R1, R3, R5, R7: 100; R_0603_1608Metric_Pad0.98x0.95mm_HandSolder
R2, R4, R6, R8: 100k; R_0603_1608Metric_Pad0.98x0.95mm_HandSolder
TP1: 12 V; TestPoint_Pad_D1.5mm
TP4: GND; TestPoint_Pad_D1.5mm

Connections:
+12V: C1.1, C2.1, J1.2, J2.1, TP1.1
CH1_CMD: J3.1, R1.1
CH1_INP: J2.2, Q1.2 (D)
CH2_CMD: J3.2, R3.1
CH2_INP: J2.3, Q2.2 (D)
CH3_CMD: J3.3, R5.1
CH3_INP: J2.4, Q3.2 (D)
CH4_CMD: J3.4, R7.1
CH4_INP: J2.5, Q4.2 (D)
GND: C1.2, C2.2, H1.1, H2.1, H3.1, H4.1, J1.1, J3.5, Q1.3 (S), Q2.3 (S), Q3.3 (S), Q4.3 (S), R2.2, R4.2, R6.2, R8.2, TP4.1
unnamed: Q1.1 (G), R1.2, R2.1
unnamed: Q2.1 (G), R3.2, R4.1
unnamed: Q3.1 (G), R5.2, R6.1
unnamed: Q4.1 (G), R7.2, R8.1

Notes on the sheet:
Additionnal
Controle_LEDStrip

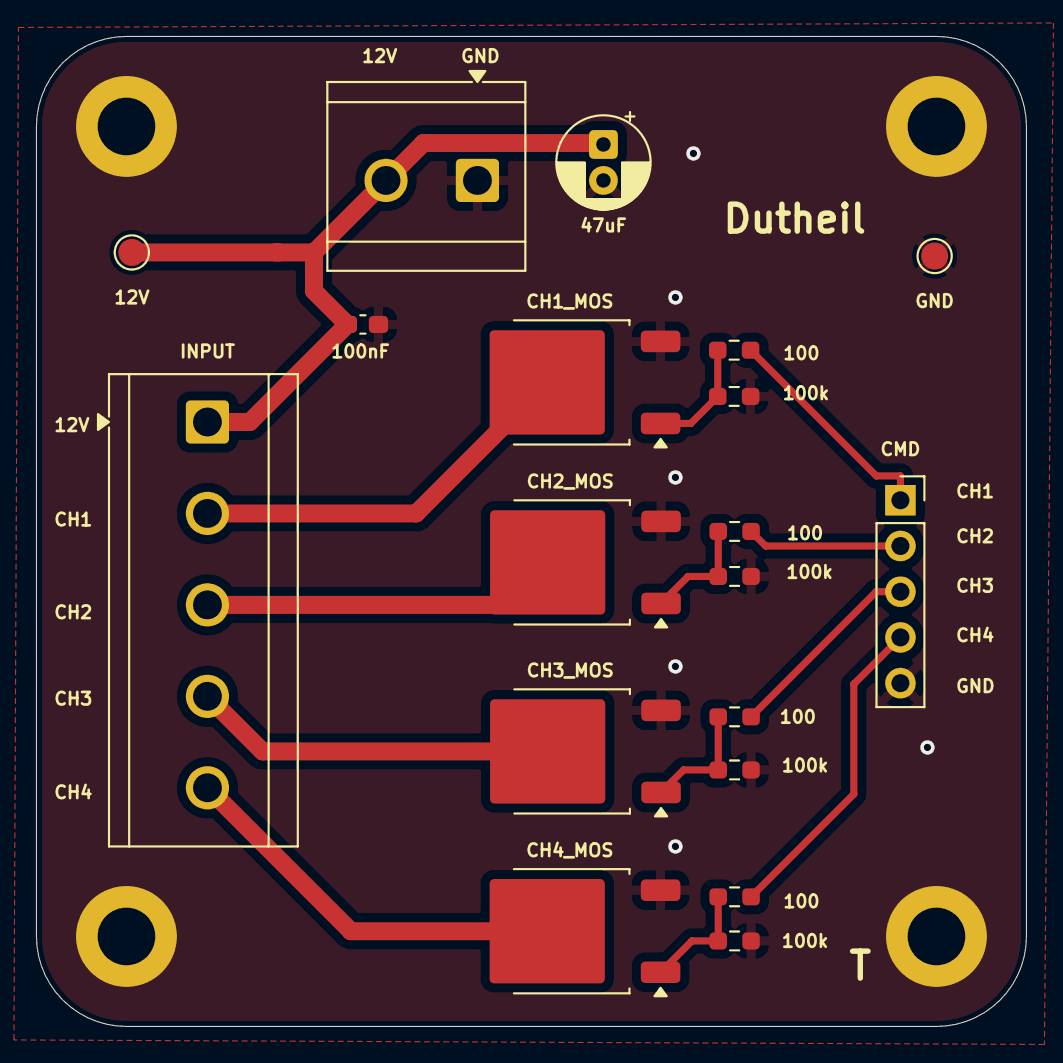
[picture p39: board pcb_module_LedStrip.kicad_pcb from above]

Board: 2 copper layers, 55.0 x 55.0 mm, 23 parts (0 on the bottom side), 14 nets.

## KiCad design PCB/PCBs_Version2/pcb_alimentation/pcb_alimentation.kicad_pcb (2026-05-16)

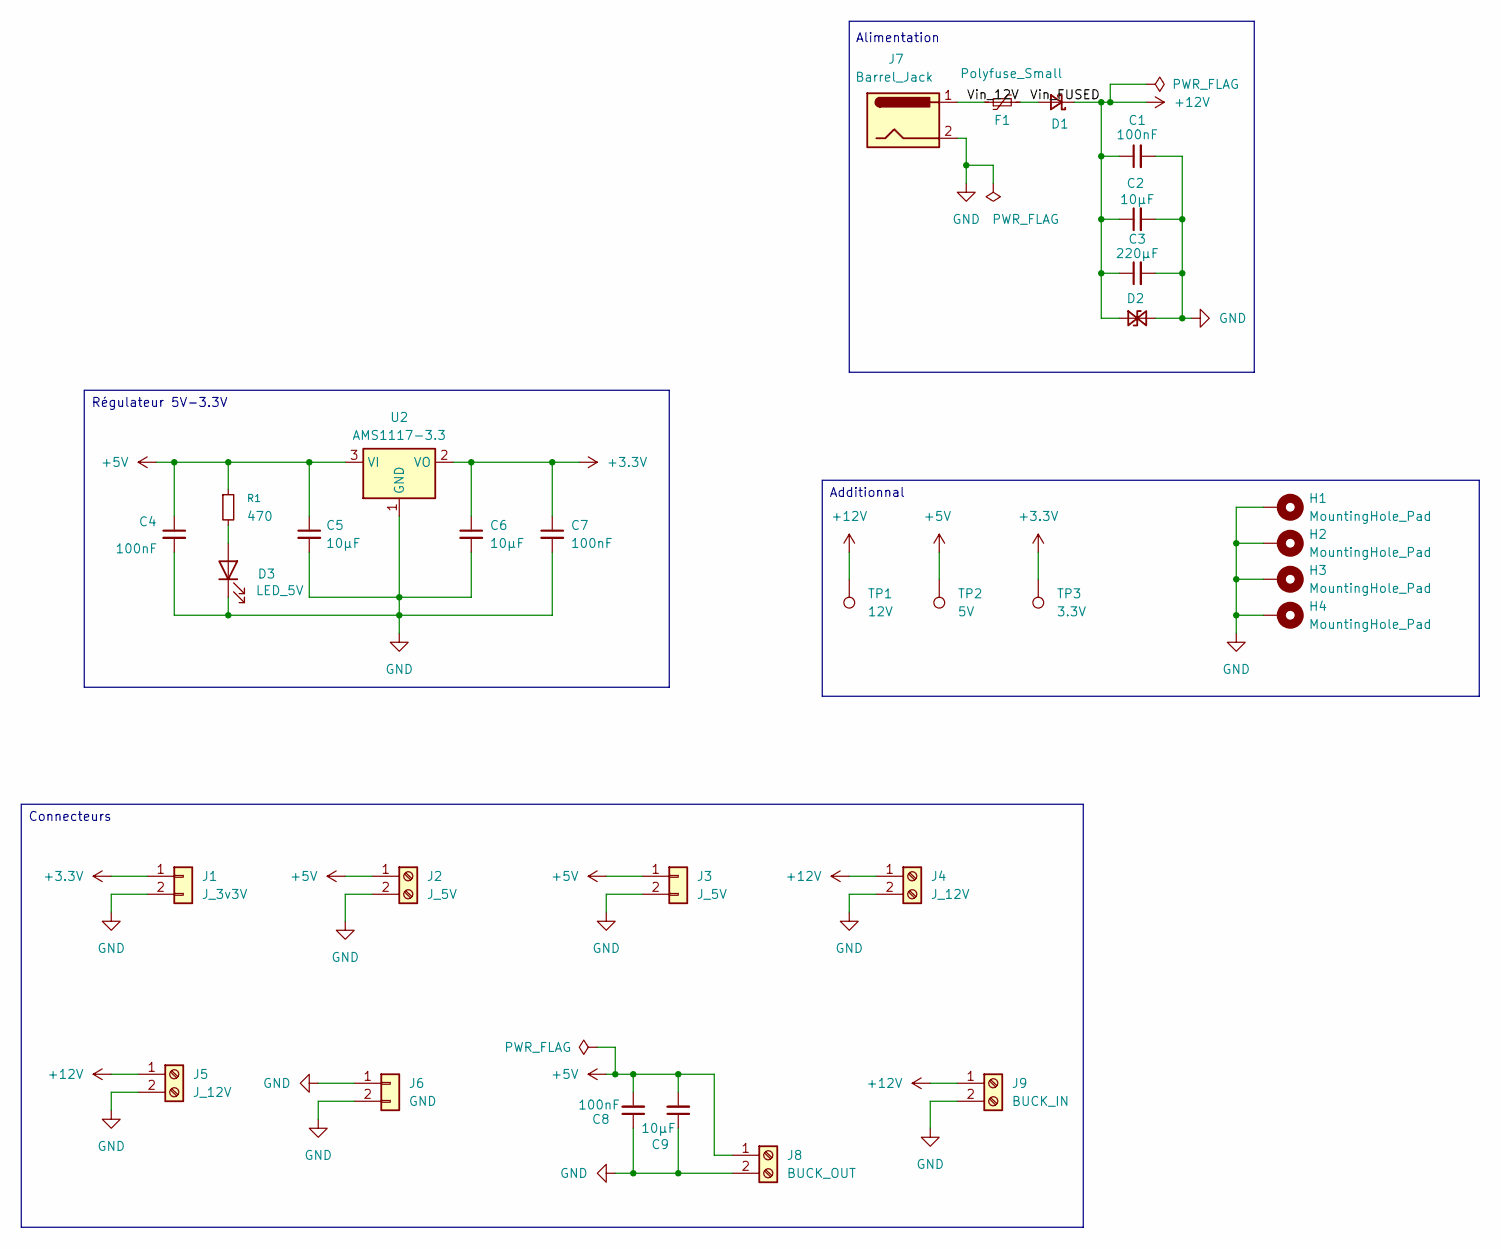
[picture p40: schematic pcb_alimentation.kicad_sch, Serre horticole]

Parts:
C1, C4, C7, C8: 100nF; C_0603_1608Metric_Pad1.08x0.95mm_HandSolder
C2, C5, C6, C9: 10µF; C_0805_2012Metric_Pad1.18x1.45mm_HandSolder
C3: 220µF; CP_Radial_D8.0mm_P3.50mm
D1: D_Schottky_Small; D_SMB_Handsoldering
D2: D_TVS_Small; D_SMB_Handsoldering
D3: LED_5V; LED_0805_2012Metric_Pad1.15x1.40mm_HandSolder
F1: Polyfuse_Small; Fuse_2920_7451Metric_Pad2.10x5.45mm_HandSolder
H1, H2, H3, H4: MountingHole_Pad; MountingHole_3.2mm_M3_DIN965_Pad
J1: J_3v3V; PinHeader_1x02_P2.54mm_Vertical
J2: J_5V; TerminalBlock_CUI_TB007-508-02_1x02_P5.08mm_Horizontal
J3: J_5V; PinHeader_1x02_P2.54mm_Vertical
J4, J5: J_12V; TerminalBlock_CUI_TB007-508-02_1x02_P5.08mm_Horizontal
J6: GND; PinHeader_1x02_P2.54mm_Vertical
J7: Barrel_Jack; BarrelJack_Horizontal
J8: BUCK_OUT; TerminalBlock_CUI_TB007-508-02_1x02_P5.08mm_Horizontal
J9: BUCK_IN; TerminalBlock_CUI_TB007-508-02_1x02_P5.08mm_Horizontal
R1: 470; R_0603_1608Metric_Pad0.98x0.95mm_HandSolder
TP1: 12V; TestPoint_Pad_D1.5mm
TP2: 5V; TestPoint_Pad_D1.5mm
TP3: 3.3V; TestPoint_Pad_D1.5mm
U2: AMS1117-3.3; SOT-223-3_TabPin2

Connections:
+3.3V: C6.1, C7.1, J1.1, TP3.1, U2.2 (VO)
+5V: C4.1, C5.1, C8.2, C9.2, J2.1, J3.1, J8.1, R1.1, TP2.1, U2.3 (VI)
+12V: C1.1, C2.1, C3.1, D1.1 (K), D2.1 (A1), J4.1, J5.1, J9.1, TP1.1
/Vin_12V: F1.1, J7.1
/Vin_FUSED: D1.2 (A), F1.2
GND: C1.2, C2.2, C3.2, C4.2, C5.2, C6.2, C7.2, C8.1, C9.1, D2.2 (A2), D3.1 (K), H1.1, H2.1, H3.1, H4.1, J1.2, J2.2, J3.2, J4.2, J5.2, J6.1, J6.2, J7.2, J8.2, J9.2, U2.1 (GND)
unnamed: D3.2 (A), R1.2

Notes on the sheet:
Alimentation
Régulateur 5V-3.3V
Additionnal
Connecteurs

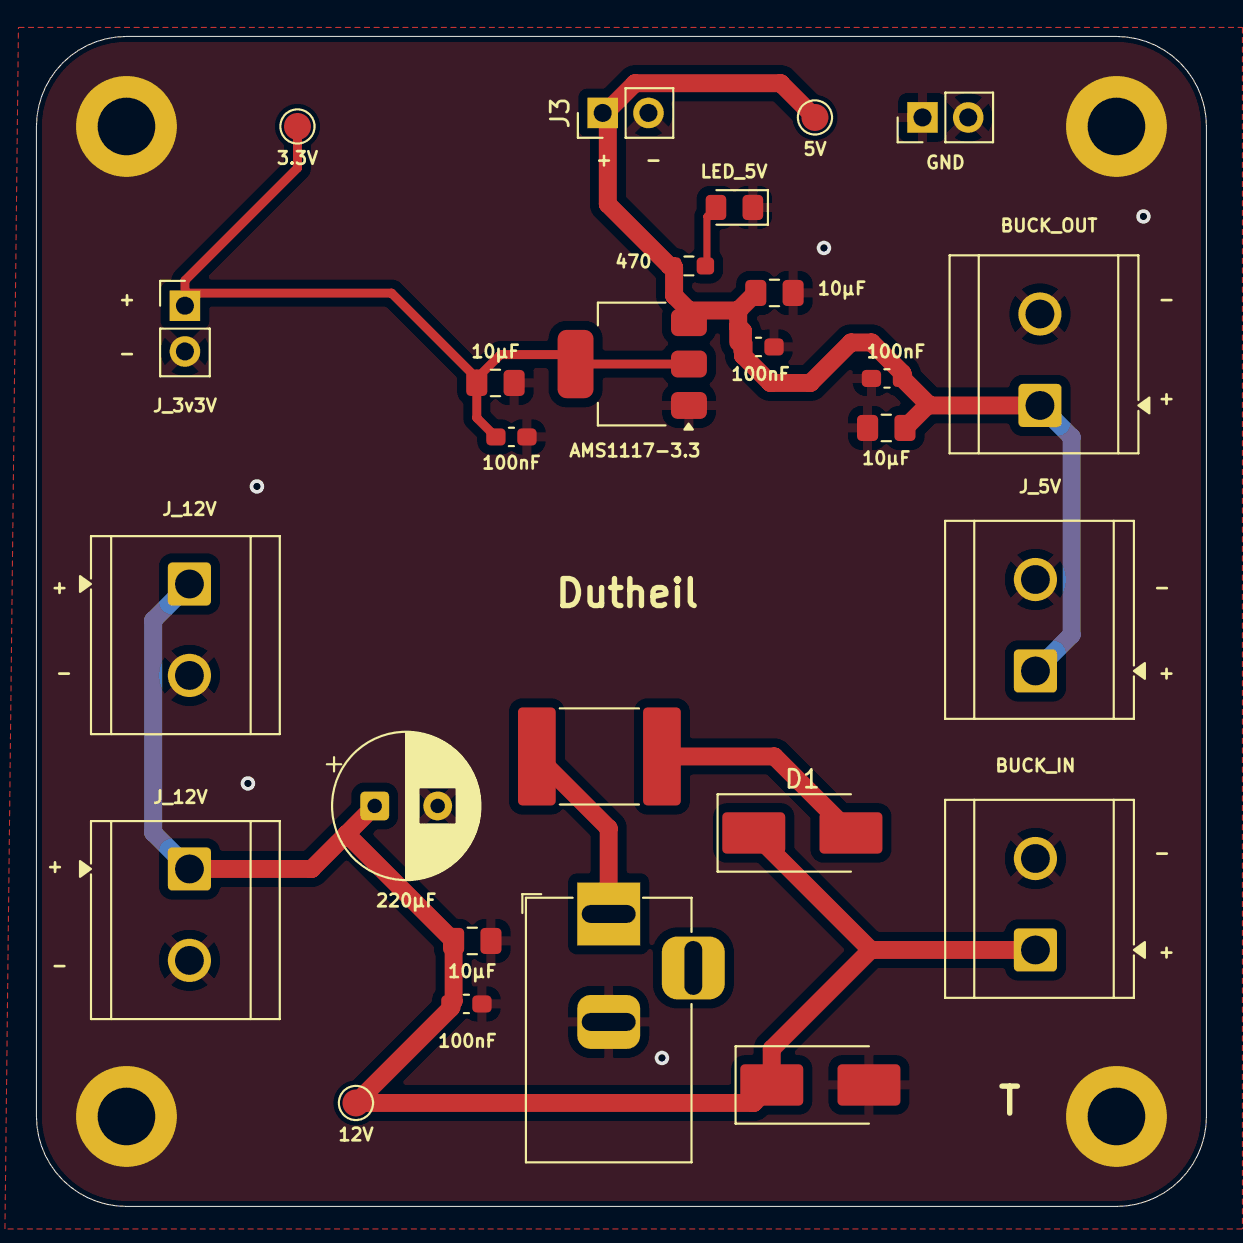
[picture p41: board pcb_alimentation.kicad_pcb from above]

Board: 2 copper layers, 65.0 x 65.0 mm, 31 parts (0 on the bottom side), 7 nets.

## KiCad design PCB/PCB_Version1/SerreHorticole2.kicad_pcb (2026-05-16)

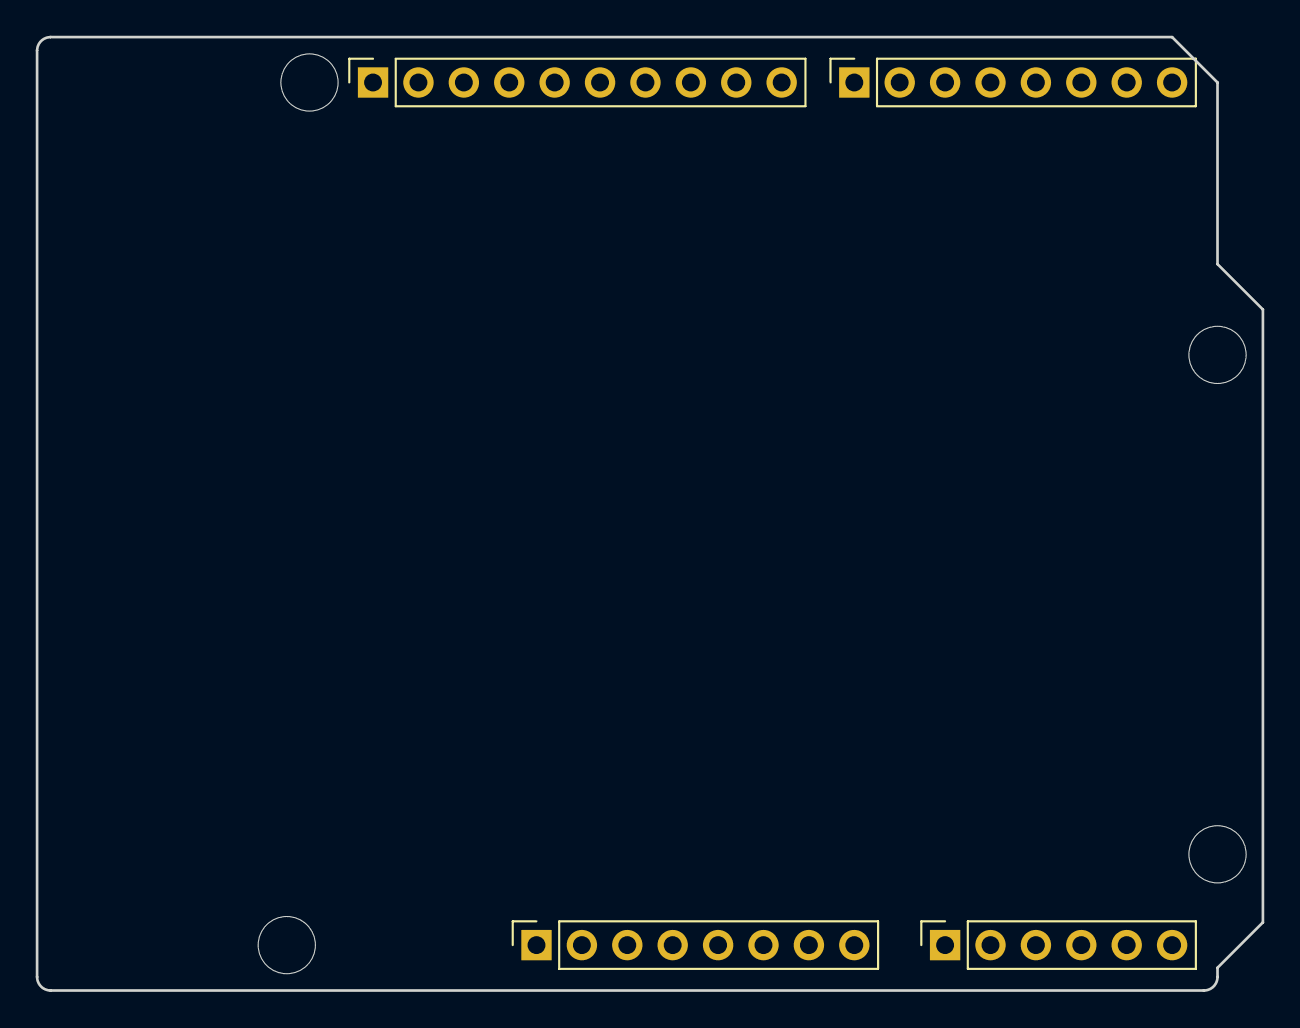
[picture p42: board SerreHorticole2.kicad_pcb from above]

Board: 2 copper layers, 68.6 x 53.3 mm, 8 parts (0 on the bottom side), 3 nets, no tracks yet.

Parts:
J1: Power; PinSocket_1x08_P2.54mm_Vertical
J2: Digital/PWM; PinSocket_1x10_P2.54mm_Vertical
J3: Analog; PinSocket_1x06_P2.54mm_Vertical
J4: Digital/PWM; PinSocket_1x08_P2.54mm_Vertical
MH1, MH2, MH3, MH4: MountingHole_3.2mm

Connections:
/SCL/A5: J2.1, J3.6
/SDA/A4: J2.2, J3.5
GND: J1.6, J1.7, J2.4

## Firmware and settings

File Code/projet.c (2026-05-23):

#include "projet.h"
#include "algo.h"
#include "stm32l4xx.h"
#include <stdint.h>
#include <stdio.h>
#include <string.h>



extern UART_HandleTypeDef huart1;
uint8_t rx;


void setup(){
	LED_PWM_Start();
}



//void loop(){
//    HAL_GPIO_WritePin(GPIOC, GPIO_PIN_6, GPIO_PIN_SET);
//    HAL_Delay(500);
//
//    HAL_GPIO_WritePin(GPIOC, GPIO_PIN_6, GPIO_PIN_RESET);
//    HAL_Delay(500);
//}

char buffer[20];
int i = 0;

void loop(void){


    if (HAL_UART_Receive(&huart1, &rx, 1, 10) == HAL_OK)
    {
        HAL_UART_Transmit(&huart1, &rx, 1, HAL_MAX_DELAY); // echo debug

        if (i < 19)
        {
            buffer[i++] = rx;
            buffer[i] = '\0';
        }

        if (strcmp(buffer, "LED_ON") == 0)
        {
            HAL_GPIO_WritePin(GPIOA, GPIO_PIN_5, GPIO_PIN_SET);
            i = 0;
            buffer[0] = '\0';
        }

        if (strcmp(buffer, "LED_OFF") == 0)
        {
            HAL_GPIO_WritePin(GPIOA, GPIO_PIN_5, GPIO_PIN_RESET);
            i = 0;
            buffer[0] = '\0';
        }

        if (strcmp(buffer, "PUMP_ON") == 0)
        {
            PUMP_ON();
            i = 0;
            buffer[0] = '\0';
        }

        if (strcmp(buffer, "PUMP_OFF") == 0)
        {
        	PUMP_OFF();
            i = 0;
            buffer[0] = '\0';
        }

        if (strcmp(buffer, "FAN_ON") == 0)
        {
            FAN_ON();
            i = 0;
            buffer[0] = '\0';
        }

        if (strcmp(buffer, "FAN_OFF") == 0)
        {
            FAN_OFF();
            i = 0;
            buffer[0] = '\0';
        }

        if(strcmp(buffer, "HUM?") == 0)
        {
        	ReadMoistureSensor();
        	i = 0;
        	buffer[0] = '\0';
        }

        if(strcmp(buffer, "LIGHT?") == 0)
        {
        	ReadLDRSensor();
            i = 0;
            buffer[0] = '\0';
        }

        if(strcmp(buffer, "TEMP?") == 0)
        {
        	ReadTemperatureSensor();
            i = 0;
            buffer[0] = '\0';
        }

        if(strncmp(buffer, "LED:", 4) == 0)
        {
            uint16_t pwm_value = atoi(&buffer[4]);
            LED_SetBrightness(pwm_value);
            i = 0;
            buffer[0] = '\0';
        }



    }



}

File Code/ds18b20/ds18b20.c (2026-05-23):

#include "ds18b20.h"

#define DS18B20_PORT GPIOB
#define DS18B20_PIN  GPIO_PIN_6

static void delay_us(uint16_t us)
{
    uint32_t start = DWT->CYCCNT;
    uint32_t ticks = us * (HAL_RCC_GetHCLKFreq() / 1000000);

    while((DWT->CYCCNT - start) < ticks);
}

static void OneWire_Pin_Output(void)
{
    GPIO_InitTypeDef GPIO_InitStruct = {0};

    GPIO_InitStruct.Pin = DS18B20_PIN;
    GPIO_InitStruct.Mode = GPIO_MODE_OUTPUT_OD;
    GPIO_InitStruct.Pull = GPIO_NOPULL;
    GPIO_InitStruct.Speed = GPIO_SPEED_FREQ_LOW;

    HAL_GPIO_Init(DS18B20_PORT, &GPIO_InitStruct);
}

static void OneWire_Pin_Input(void)
{
    GPIO_InitTypeDef GPIO_InitStruct = {0};

    GPIO_InitStruct.Pin = DS18B20_PIN;
    GPIO_InitStruct.Mode = GPIO_MODE_INPUT;
    GPIO_InitStruct.Pull = GPIO_NOPULL;

    HAL_GPIO_Init(DS18B20_PORT, &GPIO_InitStruct);
}

static uint8_t OneWire_Reset(void)
{
    uint8_t presence;

    OneWire_Pin_Output();

    HAL_GPIO_WritePin(DS18B20_PORT, DS18B20_PIN, GPIO_PIN_RESET);
    delay_us(480);

    OneWire_Pin_Input();
    delay_us(80);

    presence = HAL_GPIO_ReadPin(DS18B20_PORT, DS18B20_PIN);

    delay_us(400);

    return !presence;
}

static void OneWire_WriteBit(uint8_t bit)
{
    OneWire_Pin_Output();

    HAL_GPIO_WritePin(DS18B20_PORT, DS18B20_PIN, GPIO_PIN_RESET);

    if(bit)
    {
        delay_us(1);
        OneWire_Pin_Input();
        delay_us(60);
    }
    else
    {
        delay_us(60);
        OneWire_Pin_Input();
    }
}

static uint8_t OneWire_ReadBit(void)
{
    uint8_t bit = 0;

    OneWire_Pin_Output();

    HAL_GPIO_WritePin(DS18B20_PORT, DS18B20_PIN, GPIO_PIN_RESET);
    delay_us(2);

    OneWire_Pin_Input();
    delay_us(8);

    bit = HAL_GPIO_ReadPin(DS18B20_PORT, DS18B20_PIN);

    delay_us(50);

    return bit;
}

static void OneWire_WriteByte(uint8_t data)
{
    for(int i = 0; i < 8; i++)
    {
        OneWire_WriteBit(data & (1 << i));
    }
}

static uint8_t OneWire_ReadByte(void)
{
    uint8_t data = 0;

    for(int i = 0; i < 8; i++)
    {
        if(OneWire_ReadBit())
        {
            data |= (1 << i);
        }
    }

    return data;
}

float DS18B20_ReadTemp(void)
{
    uint8_t temp_lsb, temp_msb;
    int16_t temp;

    if(!OneWire_Reset())
    {
        return -127.0;
    }

    OneWire_WriteByte(0xCC);
    OneWire_WriteByte(0x44);

    HAL_Delay(750);

    OneWire_Reset();

    OneWire_WriteByte(0xCC);
    OneWire_WriteByte(0xBE);

    temp_lsb = OneWire_ReadByte();
    temp_msb = OneWire_ReadByte();

    temp = (temp_msb << 8) | temp_lsb;

    return (float)temp / 16.0;
}

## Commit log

2026-05-16 ajout des fichiers PCB
    [SerreHorticole2.kicad_pcb, SerreHorticole2.kicad_sch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]
2026-05-20 Ajout des test des composants version 1
2026-05-22 Petits changements de maquette PCB
2026-05-24 ajout de la diapo
